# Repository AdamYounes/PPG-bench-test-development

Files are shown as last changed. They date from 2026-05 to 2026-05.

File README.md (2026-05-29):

# Development and Validation of a Controlled Bench-Test Setup for PPG-Based Heart-Rate Sensors

This repository contains the data and Python analysis scripts for my Bachelor's thesis in Medical Technology at KTH Royal Institute of Technology.

## Project Overview
The aim of this project was to develop and validate a controlled bench-test setup that acts as a repeatable Photoplethysmography (PPG) signal source for wrist-worn, heart rate monitors. 

Validating PPG sensors on human subjects introduces uncontrollable variables like motion artifacts and ambient light. To bypass this, the project introduces two complementary laboratory setups driven by a Tektronix AFG 1022 Arbitrary Function Generator:
* **Light Emitting Setup:** Generates a synthesized PPG signal through an LED, utilizing a MOSFET to gate the LED so it only turns on in sync with the device's own sampling window.
* **Light Modulating Setup:** Attenuates the device's own emitted light via a twisted-nematic (TN) liquid-crystal shutter.

Both setups were validated against commercial devices (Polar Verity Sense, Apple Watch Series 9, Garmin Forerunner 255, and Wahoo TICKR Fit) across an exercise range of 60 to 210 bpm.

## Installation & Setup

If you intend to run the hardware communication script (`afg_connection.py`) to control the Tektronix AFG, you must configure your environment properly:

1. **Install NI-VISA:** You must install the NI-VISA backend from National Instruments for your operating system. The Python library relies on this backend to communicate over USB.
2. **Install Python Dependencies:** Install the required libraries using pip:
   ```bash
   pip install pyvisa pandas numpy matplotlib scipy tektronix_func_gen

## Printing Specifications

The printing specifications for the provided stl files are the following : 
* Printer : Elegoo Neptune 4(FDM)
* Filament type : 1.75 mm PLA
* Tempetures : 220°C(Extruder); 60°C(Bed)
* Layer height : 0.2 mm
* Infill : 20%
* Supports : None

## Repository Structure

* `afg_connection.py`: PyVISA script used to send commands and custom waveforms to the Tektronix AFG 1022, and to automate the linearity voltage sweeps.
* `plot_setup_response.py`: Characterizes the linear operating zones for both the LED emission and LCD attenuation setups.
* `plot_three_datasets.py`: Generates comparative plots of raw intensity data and ambient light readings across multiple datasets.
* `/compute_acdc`: Contains the `compute_acdc.py` script and the `/Wrist_data` folder used to isolate the cardiac component and calculate the peak-to-peak pulse amplitude (ACpp).
* `/PPGLCD_response`: Contains the data logs from the LCD shutter attenuation tests.
* `/PPGLED_response`: Data logs from the active LED setup linearity tests.
* `/HRvsPPG_data`: Contains the heart rate logs and raw PPG output folders captured during steady-state validation at 60, 90, 120, 180, and 210 bpm.
* `/3D CAD files`: Contains the Autodesk Fusion 360 schematics and STL files for 3D printing the test enclosures used in both setups.

## Author
Adam Younes 
Degree project in Medical Technology (First cycle, 15 credits)
KTH Royal Institute of Technology

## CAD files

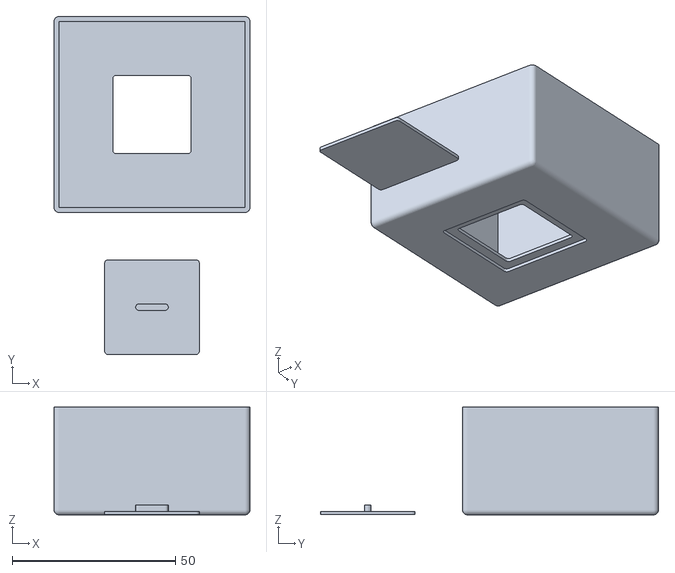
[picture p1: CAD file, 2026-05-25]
3D CAD files/PPG_LCD_Setup_Cover.stl
60.0 x 103.5 x 33.0

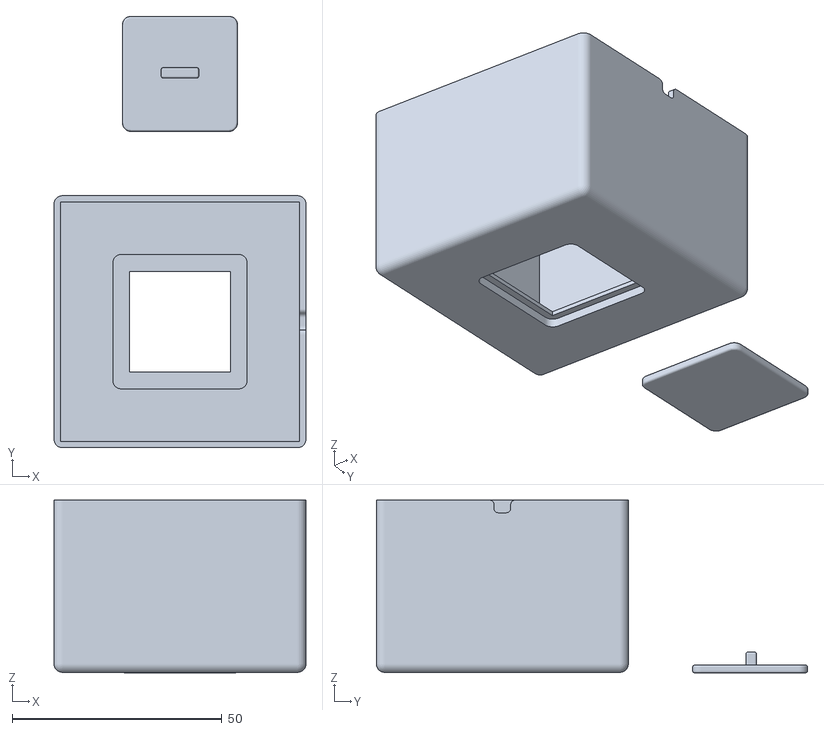
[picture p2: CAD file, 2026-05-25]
3D CAD files/PPG_LED_Setup_Cover.stl
60.0 x 102.7 x 41.1

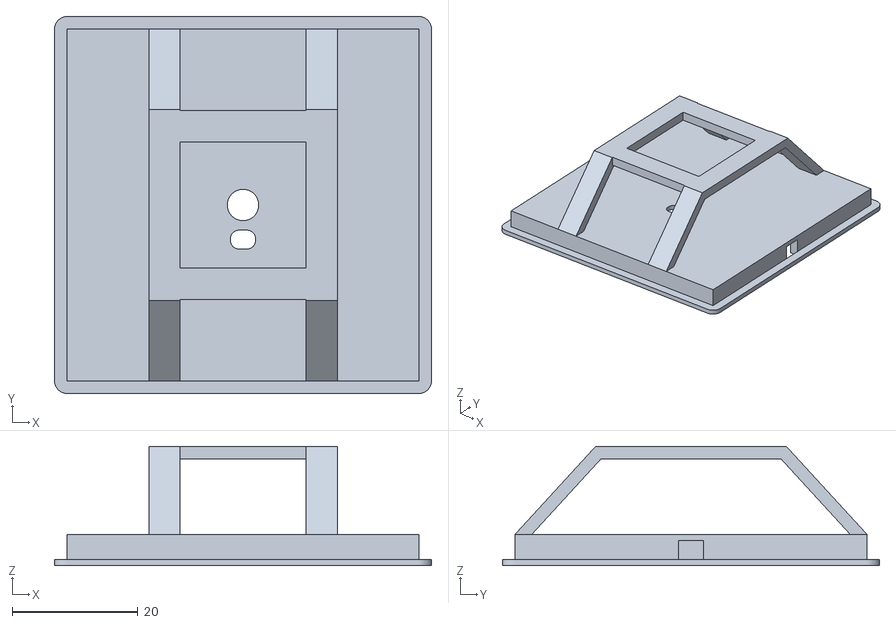
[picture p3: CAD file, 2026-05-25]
3D CAD files/PPG_LED_Setup_Base.stl
60.0 x 60.0 x 19.0

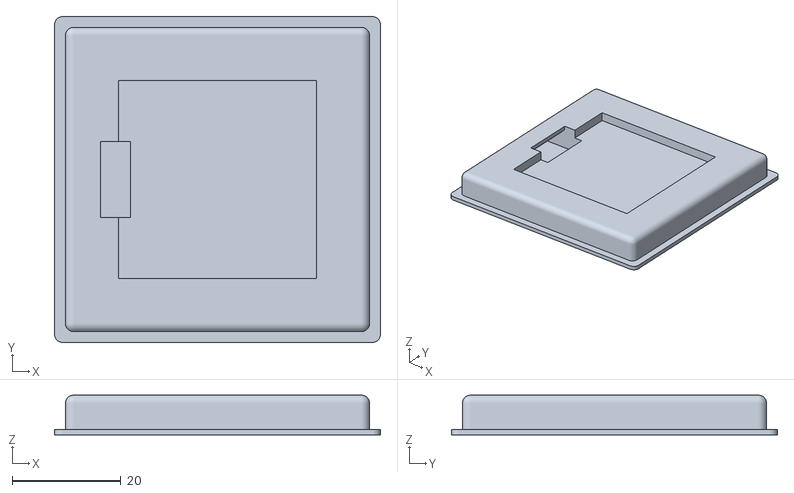
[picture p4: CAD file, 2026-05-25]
3D CAD files/PPG_LCD_Setup_Base.stl
60.0 x 60.0 x 7.30

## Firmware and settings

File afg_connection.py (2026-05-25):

"""
Configured for Tektronix AFG 1022
Scripts used for performing response tests by sending commands to the AFG through PyVisa.
Run ppg_wave_setup to set custom waveform to the desired memory slot.
Requires PyVisa library to be downloaded, as well as install NI-VISA backend to configure usb port.
"""

import asyncio
from datetime import datetime, timedelta
import os
from pathlib import Path
import sys
import time
from tektronix_func_gen import FuncGen
import tektronix_func_gen as tfg
import numpy as np
import pandas as pd
import matplotlib.pyplot as plt
import csv
import pyvisa

def set_custom_waveform(
    self,
    waveform: np.ndarray,
    normalise: bool = True,
    memory_num: int = 0,
    verify: bool = True,
    print_progress: bool = True,
):
    """Transfer waveform data to edit memory and then user memory.
    NOTE: Will overwrite without warnings

    Parameters
    ----------
    waveform : ndarray
        Either unnormalised arbitrary waveform (then use `normalise=True`),
        or ints spanning the resolution of the function generator
    normalise : bool
        Choose whether to normalise the waveform to ints over the
        resolution span of the function generator
    memory_num : str or int {0,...,255}, default 0
        Select which user memory to copy to
    verify : bool, default `True`
        Verify that the waveform has been transferred and is what was sent
    print_progress : bool, default `True`

    Returns
    -------
    waveform : ndarray
        The normalised waveform transferred

    Raises
    ------
    ValueError
        If the waveform is not within the permitted length or value range
    RuntimeError
        If the waveform transferred to the instrument is of a different
        length than the waveform supplied
    """
    if not 0 <= memory_num <= self._max_waveform_memory_user_locations:
        raise ValueError(
            f"The memory location {memory_num} is not a valid "
            "memory location for this model"
        )
    # Check if waveform data is suitable
    if print_progress:
        print("Check if waveform data is suitable..", end=" ")
    self._check_arb_waveform_length(waveform)
    try:
        self._check_arb_waveform_type_and_range(waveform)
    except ValueError as err:
        if print_progress:
            print(f"\n  {err}")
            print("Trying again normalising the waveform..", end=" ")
        waveform = self._normalise_to_waveform(waveform)
    if print_progress:
        print("ok")
        print("Transfer waveform to function generator..", end=" ")
    # Transfer waveform
    self._inst.write_binary_values(
        "DATA:DATA EMEMory,", waveform, datatype="H", is_big_endian=True
    )
    # Check for errors and check lengths are matching
    transfer_error = self.get_error()
    emem_wf_length = self.query("DATA:POINts? EMEMory")
    if emem_wf_length == "" or not int(emem_wf_length) == len(waveform):
        msg = (
            f"Waveform in temporary EMEMory has a length of {emem_wf_length}"
            f", not of the same length as the waveform ({len(waveform)})."
            f"\nError from the instrument: {transfer_error}"
        )
        raise RuntimeError(msg)
    if print_progress:
        print("ok")
        print(f"Copy waveform to USER{memory_num}..", end=" ")
    self.write(f"DATA:COPY USER{memory_num},EMEMory")
    if print_progress:
        print("ok")
    if verify:
        if print_progress:
            print(f"Verify waveform USER{memory_num}..")
        if f"USER{memory_num}" in self.get_waveform_catalogue():
            verif = self._verify_waveform(
                waveform,
                memory_num,
                normalise=normalise,
                print_result=print_progress,
            )
            if not verif[0]:
                raise RuntimeError(
                    f"USER{memory_num} does not contain the waveform"
                )
        else:
            raise RuntimeError(f"USER{memory_num} is empty")
    return waveform


def ppg_wave_setup(visa_address):
    import math
    pi = math.pi
    # Generate a time array
    time = np.linspace(1.07, 1.72, 1000)
    # Calculate the waveform
    data = 500 * np.cos(2 * pi * 1.5 * time) - 250 * np.sin(4 * pi * 1.5 * time) * -1 # Multiply by negative 1 to inverse it. Remove "*-1" for LCD.
 

    with tfg.FuncGen(visa_address) as fgen:
        fgen.set_custom_waveform(waveform = data, memory_num=1, verify=True)



def control(fgen: FuncGen, freq):
    fgen.ch1.set_frequency(freq, unit="Hz")


def set_initial_settings(fgen: FuncGen, freq):
    fgen.ch1.set_function("USER0")
    fgen.ch1.set_frequency(freq, unit="Hz")
    fgen.ch1.set_offset(3, unit="V")
    fgen.ch1.set_amplitude(4)
    fgen.ch1.set_output("ON")
    fgen.ch1.print_settings()

def run_LED_linearity_test(inst):
    # Test parameters
    START_V_PEAK = 0.0
    END_V_PEAK = 1.0    
    STEP_V_PEAK = 0.1      
    INTERVAL = 1.0      
    SYNC_DURATION = 2 
    try:
        inst.write('OUTPUT1:IMPEDANCE INF') 
        results = []

        # --- PULSE 1: START SYNC (5V Peak / 10Vpp) ---
        print(f"Pulse: START (2.2V Peak for {SYNC_DURATION}s)")
        inst.write('SOURCE1:FUNCTION:SHAPE DC')
        inst.write(f'SOURCE1:VOLTAGE:LEVEL:IMMEDIATE:OFFSET {END_V_PEAK}V')
        inst.write('OUTPUT1:STATE ON')
        results.append([datetime.now().strftime('%H:%M:%S.%f'), {END_V_PEAK}])
        time.sleep(SYNC_DURATION)

        # --- LINEARITY SWEEP (0V to 5V Peak) ---
        print(f"Sweep: BEGINNING at {START_V_PEAK}...")
        current_peak = START_V_PEAK
        while current_peak <= (END_V_PEAK + 0.01):

            inst.write('SOURCE1:FUNCTION:SHAPE DC')
            inst.write(f'SOURCE1:VOLTAGE:LEVEL:IMMEDIATE:OFFSET {current_peak}V')

            ts = datetime.now().strftime('%H:%M:%S.%f')
            results.append([ts, round(current_peak, 2)])
            
            print(f"[{ts}] Peak: {current_peak:.2f}V")
            time.sleep(INTERVAL)
            current_peak += STEP_V_PEAK

        # --- PULSE 2: END SYNC / DISCHARGE (True 0V DC) ---
        # We switch to DC function to force exactly 0V across terminals
        print(f"Pulse: END / DISCHARGE (0V DC for {SYNC_DURATION}s)")
        inst.write('SOURCE1:FUNCTION:SHAPE DC') # Switch to DC mode
        inst.write('SOURCE1:VOLTAGE:LEVEL:IMMEDIATE:OFFSET 0V') # Force 0V
        
        ts_end = datetime.now().strftime('%H:%M:%S.%f')
        results.append([ts_end, 0.0])
        time.sleep(SYNC_DURATION)

        # 4. Cleanup
        inst.write('OUTPUT1:STATE OFF')
        print("Test Complete. Output OFF.")

        # Save Log
        filename = "PPG_LEDTEST_9.csv"
        with open(filename, 'w', newline='') as f:
            writer = csv.writer(f)
            writer.writerow(['Timestamp', 'Peak_Voltage_V'])
            writer.writerows(results)
        print(f"Log saved to {filename}")

    except Exception as e:
        print(f"Error: {e}")
    finally:
        if 'inst' in locals():
            inst.close()

def run_LCD_linearity_test(inst):
    # Test parameters
    START_V_PEAK = 0.0
    END_V_PEAK = 5.0    
    STEP_V_PEAK = 0.1      
    INTERVAL = 1.0      
    SYNC_DURATION = 2.0 
    FREQ = "60Hz"
    try:
        inst.write('OUTPUT1:IMPEDANCE INF') 
        results = []

        # --- PULSE 1: START SYNC (5V Peak / 10Vpp) ---
        print(f"Pulse: START (5V Peak for {SYNC_DURATION}s)")
        inst.write('SOURCE1:FUNCTION:SHAPE SQUARE')
        inst.write(f'SOURCE1:FREQUENCY:FIXED {FREQ}')
        inst.write('SOURCE1:VOLTAGE:LEVEL:IMMEDIATE:OFFSET 0V')
        inst.write('SOURCE1:VOLTAGE:AMPLITUDE 10.0VPP')
        inst.write('OUTPUT1:STATE ON')
        results.append([datetime.now().strftime('%H:%M:%S.%f'), 5.0])
        time.sleep(SYNC_DURATION)

        # --- LINEARITY SWEEP (0V to 5V Peak) ---
        print(f"Sweep: BEGINNING at {FREQ}...")
        current_peak = START_V_PEAK
        while current_peak <= (END_V_PEAK + 0.01):
            v_pp = current_peak * 2
            if v_pp < 0.001:
                inst.write('SOURCE1:FUNCTION:SHAPE DC')
                inst.write('SOURCE1:VOLTAGE:LEVEL:IMMEDIATE:OFFSET 0V')
            else:
                inst.write('SOURCE1:FUNCTION:SHAPE SQUARE')
                inst.write(f'SOURCE1:VOLTAGE:AMPLITUDE {v_pp}VPP')
            
            ts = datetime.now().strftime('%H:%M:%S.%f')
            results.append([ts, round(current_peak, 2)])
            
            print(f"[{ts}] Peak: {current_peak:.2f}V")
            time.sleep(INTERVAL)
            current_peak += STEP_V_PEAK

        # --- PULSE 2: END SYNC / DISCHARGE (True 0V DC) ---
        # We switch to DC function to force exactly 0V across terminals
        print(f"Pulse: END / DISCHARGE (0V DC for {SYNC_DURATION}s)")
        inst.write('SOURCE1:FUNCTION:SHAPE DC') # Switch to DC mode
        inst.write('SOURCE1:VOLTAGE:LEVEL:IMMEDIATE:OFFSET 0V') # Force 0V
        
        ts_end = datetime.now().strftime('%H:%M:%S.%f')
        results.append([ts_end, 0.0])
        time.sleep(SYNC_DURATION)

        # 4. Cleanup
        inst.write('OUTPUT1:STATE OFF')
        print("Test Complete. Output OFF.")

        # Save Log
        filename = "PPG_OPTEST_3.csv"
        with open(filename, 'w', newline='') as f:
            writer = csv.writer(f)
            writer.writerow(['Timestamp', 'Peak_Voltage_V'])
            writer.writerows(results)
        print(f"Log saved to {filename}")

    except Exception as e:
        print(f"Error: {e}")
    finally:
        if 'inst' in locals():
            inst.close()



# --- EXECUTION ---
rm = pyvisa.ResourceManager()
VISA_ADDRESS = 'USB::0x0699::0x0353::2217045::INSTR' # Change depending on your own AFG Visa address
afg = rm.open_resource(VISA_ADDRESS)


if __name__ == "__main__":
    run_LCD_linearity_test(afg)
#    run_LED_linearity_test(afg)
#    ppg_wave_setup(visa_address)

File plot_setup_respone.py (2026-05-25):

#!/usr/bin/env python3
"""PPG linearity & operating-zone characterisation (LED / LCD).

Each trial: an AFG sync pulse at the start (used only to time-align the two
logs, never plotted) followed by a voltage staircase. It handles both the LED rig (signal rises with V) and the
LCD rig (signal falls with V). Set SETUP and run.
Script was co-created with github copilot.
"""

import os
import numpy as np
import pandas as pd
import matplotlib.pyplot as plt
from scipy.stats import linregress

# --- configuration ---------------------------------------------------------
SETUP = "LCD"

CONFIG = {
    "LED": dict(
        data_dir="PPGLED_response/", channel="PPG0", v_min=0.10, v_max=1.10,
        ylabel="Normalised emitted intensity",
        tests=[("PPG_LEDTEST_1.csv", "PPG_20260519_221133.txt"),
               ("PPG_LEDTEST_2.csv", "PPG_20260519_221238.txt"),
               ("PPG_LEDTEST_3.csv", "PPG_20260519_221322.txt")],
    ),
    "LCD": dict(
        data_dir="PPGLCD_response", channel="PPG0", v_min=0.10, v_max=4.90,
        ylabel="Normalised transmittance",
        tests=[("PPG_LCDTEST_1.csv", "PPG_20260517_1.txt"),
               ("PPG_LCDTEST_2.csv", "PPG_20260517_2.txt"),
               ("PPG_LCDTEST_3.csv", "PPG_20260517_3.txt")],
    ),
}

R2_MIN, MIN_SPAN, MIN_PTS = 0.99, 0.20, 4   # linearity criteria
SETTLE, TAIL = 0.30, 0.10                   # dwell-sampling window fractions


# --- per-trial processing ---------------------------------------------------
def process(csv_file, txt_file, cfg):
    """Return a tidy frame (V, S, T) for one trial, or None on failure."""
    csv_p = os.path.join(cfg["data_dir"], csv_file)
    txt_p = os.path.join(cfg["data_dir"], txt_file)
    if not (os.path.exists(csv_p) and os.path.exists(txt_p)):
        return None

    afg = pd.read_csv(csv_p, dtype={"Timestamp": "string"})
    ts = pd.to_datetime(afg["Timestamp"], format="%H:%M:%S.%f")
    afg["t"] = ts.dt.hour * 3600 + ts.dt.minute * 60 + ts.dt.second + ts.dt.microsecond / 1e6
    afg["V"] = pd.to_numeric(afg["Peak_Voltage_V"], errors="coerce").fillna(0.0)

    ppg = pd.read_table(txt_p, sep=r"\s+", comment="#", engine="python")
    ppg["t"] = ppg["TIMESTAMP"] / 1e9
    s = ppg[cfg["channel"]].to_numpy(float)

    # Start-anchored sync: align the AFG marker (row 0) with the first PPG
    # excursion past 30% of the signal range, works for rise or fall.
    base, rng = np.median(s[:5]), s.max() - s.min()
    if rng == 0:
        return None
    rise = np.argmax(np.abs(s - base) > 0.30 * rng)
    ppg["ta"] = ppg["t"] - (ppg["t"].iloc[rise] - afg["t"].iloc[0])

    # Staircase starts after the marker returns to ~0 V.
    end = np.argmax(afg["V"].to_numpy()[1:] <= cfg["v_min"]) + 1
    stair = afg.iloc[end:].reset_index(drop=True)
    nxt = stair["t"].shift(-1)
    nxt = nxt.fillna(stair["t"] + (nxt - stair["t"]).median())

    rows = []
    for v, t0, t1 in zip(stair["V"], stair["t"], nxt):
        if not (cfg["v_min"] <= v <= cfg["v_max"]) or (t1 - t0) < 0.2:
            continue
        seg = ppg[(ppg["ta"] >= t0 + SETTLE * (t1 - t0)) & (ppg["ta"] <= t1 - TAIL * (t1 - t0))]
        if not seg.empty:
            rows.append((v, seg[cfg["channel"]].mean()))
    if not rows:
        return None

    agg = pd.DataFrame(rows, columns=["V", "S"]).groupby("V", as_index=False).mean()
    lo, hi = agg["S"].min(), agg["S"].max()
    agg["T"] = (agg["S"] - lo) / (hi - lo) if hi != lo else 0.0
    return agg


def linear_window(agg):
    """Widest voltage window with R^2 >= R2_MIN; ties broken by R^2."""
    v, t, n = agg["V"].to_numpy(), agg["T"].to_numpy(), len(agg)
    best = (None, None, None, -1.0, -1.0)  # lo, hi, reg, span, r2
    for i in range(n - MIN_PTS + 1):
        for j in range(i + MIN_PTS - 1, n):
            if abs(t[j] - t[i]) < MIN_SPAN:
                continue
            reg = linregress(v[i:j + 1], t[i:j + 1])
            r2, span = reg.rvalue ** 2, abs(v[j] - v[i])
            if r2 >= R2_MIN and (span, r2) > (best[3], best[4]):
                best = (v[i], v[j], reg, span, r2)
    return best[:3]


# --- run + plot -------------------------------------------------------------
def main():
    cfg = CONFIG[SETUP]
    fig, (axa, axb) = plt.subplots(1, 2, figsize=(14, 6))
    colors = plt.cm.tab10(np.linspace(0, 0.9, len(cfg["tests"])))
    zones, fits = [], []

    for (csv_file, txt_file), c in zip(cfg["tests"], colors):
        agg = process(csv_file, txt_file, cfg)
        if agg is None:
            print(f"[skip] {txt_file}")
            continue
        name = os.path.splitext(os.path.basename(txt_file))[0]
        axa.plot(agg["V"], agg["S"], "o-", color=c, ms=4, lw=1.5, label=name)

        lo, hi, reg = linear_window(agg)
        if reg is None:
            axb.plot(agg["V"], agg["T"], "o--", color=c, ms=4, lw=1, alpha=.5, label=name)
            continue
        lo, hi = sorted((lo, hi))
        zones.append((lo, hi)); fits.append((reg.slope, reg.intercept))
        axb.plot(agg["V"], agg["T"], "o-", color=c, ms=4, lw=1.5, alpha=.75,
                 label=f"{name} ({lo:.2f}-{hi:.2f} V)")

    if zones:
        vlo, vhi = np.mean([z[0] for z in zones]), np.mean([z[1] for z in zones])
        m, b = np.mean([f[0] for f in fits]), np.mean([f[1] for f in fits])
        xs = np.linspace(max(0, vlo - .2), min(5, vhi + .2), 50)
        axb.plot(xs, m * xs + b, color="crimson", lw=2.5, label="Avg linear system fit")
        axb.axvspan(vlo, vhi, alpha=.12, color="darkorange",
                    label=f"Linear zone (R²≥{R2_MIN}): {vlo:.2f}-{vhi:.2f} V")
        print(f"{SETUP}: linear zone {vlo:.2f}-{vhi:.2f} V, slope {m:.3f} units/V")

    axa.set(xlabel="AFG Peak Voltage (V)", ylabel="Raw sensor output", title="Graph A : Raw Sensor Output")
    axb.set(xlabel="AFG Peak Voltage (V)", ylabel=cfg["ylabel"],
            title=f"Graph B : Linear Operating Zone (R²≥{R2_MIN})", ylim=(-.05, 1.05))
    for ax in (axa, axb):
        ax.grid(True, ls=":", alpha=.6); ax.legend(fontsize=8)
    plt.tight_layout()
    plt.savefig(f"linearity_{SETUP}.png", dpi=200, bbox_inches="tight")
    plt.show()


if __name__ == "__main__":
    main()

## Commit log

2026-05-25 Scripts and data uploaded
    [PPG_LEDTEST_1.csv, PPG_LEDTEST_2.csv, PPG_LEDTEST_3.csv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]
2026-05-25 Uploading the 3D files
    [PPG_LCD_Setup_Base.stl, PPG_LCD_Setup_Cover.stl, PPG_LED_Setup_Base.stl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]
2026-05-29 Added printer settings
